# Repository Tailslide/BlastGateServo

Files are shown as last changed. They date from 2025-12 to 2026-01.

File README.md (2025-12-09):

# BlastGateServo
Blast gate servo controller for Arduino

See 3d printed parts at : https://www.thingiverse.com/thing:3301904

## Features
* Allows a single push button to switch between different blast gates, with only a single one open at a time
* Currently open blast gate is indicated by an LED
* Optional automatic control using AC current sensors to detect active tools
* Debug output support for troubleshooting
* Configurable servo positions for precise gate control

## Hardware Requirements
* Arduino Uno (R3 or R4)
* A servo for each blast gate (up to 5)
* One push button
* Optional: An LED for each blast gate
* Optional: AC current sensors from https://moderndevice.com/products/current-sensor

## Development Setup
1. Install Visual Studio Code
2. Install PlatformIO IDE extension for VSCode
3. Open this project folder in VSCode
4. PlatformIO will automatically install required dependencies:
   - Servo library (v1.2.1 or later)

## Building and Uploading
1. Connect your Arduino Uno to your computer via USB
2. In VSCode:
   - Click the PlatformIO icon in the sidebar
   - Under Project Tasks:
     - Click "Build" to compile
     - Click "Upload" to flash to Arduino
   - Use "Monitor" to view serial output (when debugging is enabled)
3. Serial monitor is configured at 9600 baud

## Operation Modes
* Normal Mode: Use the push button to cycle through gates. After selecting a gate, wait briefly and it will open automatically.
* Meter Mode: For calibrating AC sensors:
  1. Power off the Arduino
  2. Press and hold the button
  3. While holding the button, power on the Arduino
  4. Release the button after power-up
  5. LEDs will now act as signal strength indicators:
     - Each LED corresponds to an AC sensor
     - Turn on a device on the cable being calibrated
     - Rotate the sensor clamp around the cable
     - LED will blink faster (or become solid) when sensor is optimally positioned
* Debug Mode: Enable detailed serial output by setting DEBUG flag (enabled by default)
* LED Test Mode: Enable by uncommenting DEBUG_LED_TEST in Configuration.h. Flashes each LED in sequence to verify connections.
* Servo Test Mode: Enable by uncommenting DEBUG_SERVO_TEST in Configuration.h. Opens and closes a specified servo with each button press without initializing other components. Set TEST_SERVO_INDEX in Configuration.h to select which servo to test (1 = first servo, 2 = second servo, etc.). Useful for testing servo functionality and calibration. The system will properly handle disabled servos (pins set to -1) by controlling only the LED while skipping servo movement.

## Configuration
All settings can be adjusted in Configuration.h:

### Basic Settings
* Number of gates (NUM_GATES) - up to 5 supported
* Number of AC sensors (NUM_AC_SENSORS) - typically one per gate
* Number of LEDs (NUM_LEDS) - typically one per gate
* Button pin assignment (BUTTON_PIN)

### Timing Settings
* CLOSE_DELAY - Time it takes for a gate to close (ms)
* OPEN_DELAY - Time after last button push to open gate (ms)
* MAX_BLINK_LEN - LED blink rate (adjusted automatically in debug mode)

### AC Sensor Settings
* NUM_OFF_SAMPLES - Number of samples for checking average sensor off values
* NUM_OFF_MAX_SAMPLES - Milliseconds to sample for max off value at startup
* AVG_READINGS - Number of readings to average when triggering gates (max 50)
* AC_SENSOR_SENSITIVITY - Trigger threshold multiplier (2.0 = twice max off reading)

### Flutter Protection Settings
The system includes comprehensive protection against AC sensor flutter that could cause rapid servo cycling and potential hardware damage:

* **AC_SENSOR_SENSITIVITY_ON** (default: 2.0) - Threshold multiplier to turn tool ON
* **AC_SENSOR_SENSITIVITY_OFF** (default: 1.5) - Threshold multiplier to turn tool OFF (creates hysteresis)
* **DEBOUNCE_STABLE_READINGS** (default: 3) - Number of consecutive stable readings required before state change
* **MIN_SERVO_INTERVAL_MS** (default: 2000) - Minimum milliseconds between operations on the same gate
* **MAX_OPS_PER_MINUTE** (default: 10) - Maximum operations per minute before emergency shutdown
* **ERROR_FLASH_INTERVAL_MS** (default: 200) - LED flash interval when in error state

#### How Flutter Protection Works
1. **Hysteresis**: Uses different thresholds for turning ON (2.0x baseline) vs turning OFF (1.5x baseline) to prevent rapid toggling around a single threshold
2. **Debouncing**: Requires 3 consecutive stable sensor readings before changing gate state, filtering out momentary noise spikes
3. **Minimum Interval with Queuing**: Enforces 2-second minimum between operations on the same gate
   - If a gate operation is requested during the cooldown period, it is automatically queued
   - The queued operation executes automatically once the minimum interval expires
   - This ensures responsive operation while preventing rapid cycling
   - Example: If you turn on a tool immediately after turning it off, the gate will open automatically 2 seconds later
4. **Rate Limiting**: Tracks operations per minute and enters error state if limit exceeded
5. **Error State**: When too many operations detected (flutter condition):
   - All LEDs flash rapidly in error pattern
   - All automatic gate operations are disabled
   - System requires restart to recover
   - Alerts user to problematic sensor or configuration issue

### Pin Assignments
* Servo pins (SERVO_PIN_1 through SERVO_PIN_5)
  * Set any servo pin to -1 to disable that servo while maintaining the gate numbering
  * Example: Setting SERVO_PIN_2 to -1 disables the second servo but keeps gate 3 as "gate 3" in the UI
* AC sensor pins (AC_SENSOR_PIN_1 through AC_SENSOR_PIN_5)
* LED pins (LED_PIN_1 through LED_PIN_5)

### Servo Position Configuration
* SERVO_MAX_x - Maximum position for each servo (typically 180 degrees)
* SERVO_MIN_x - Minimum position for each servo (typically 0 degrees)
* GATE_CLOSED_AT_MAX_x - Determines gate orientation:
  * Set to true (default) if gate is closed when servo is at max position
  * Set to false if gate is open when servo is at max position (inverted)
* Set any servo's MAX/MIN values even if the pin is disabled (-1) to maintain consistent configuration

## Project Structure
* src/BlastGateServo.cpp - Main program file with setup and loop
* include/Configuration.h - All user configurable settings
* include/GateServos.h/cpp - Servo control and position management
* include/AcSensors.h/cpp - AC current sensor reading and threshold detection
* include/Debug.h - Debug output macros and configuration
* platformio.ini - PlatformIO project configuration and library dependencies

## Changes
* Created 2019-01-02 - Greg Pringle
* Updated 2019-01-20 - Greg Pringle - Added AC sensor support
* Updated 2025-01-26 - Added VSCode/PlatformIO support
* Updated 2025-02-16 - Added detailed configuration documentation and converted to proper C++ structure
* Updated 2025-02-26 - Added support for disabling specific servos (set pin to -1) while maintaining gate numbering
* Updated 2025-02-26 - Fixed button timing logic to properly open gates after selection
* Updated 2025-02-26 - Improved timer logic to ensure gates open/close reliably, reduced OPEN_DELAY to 800ms
* Updated 2025-02-26 - Implemented proper button debouncing and state machine for more reliable operation
* Updated 2025-02-26 - Fixed issue with servos not moving when button was pressed
* Updated 2025-02-26 - Enhanced gate selection to automatically skip disabled gates when cycling through options
* Updated 2025-02-27 - Fixed compiler warnings in Configuration.h (removed redundant header guard and corrected version number format) and in GateServos.h (fixed signed/unsigned comparison by changing opendelay type to unsigned long)
* Updated 2025-02-27 - Added gate orientation configuration (GATE_CLOSED_AT_MAX_x) to support different physical gate setups where gates may be open when up or closed when up
* Updated 2025-12-08 - Implemented comprehensive flutter protection system to prevent AC sensor flutter from damaging hardware:
  - Added hysteresis (different ON/OFF thresholds) to prevent rapid state toggling
  - Implemented debouncing requiring 3 consecutive stable readings before state change
  - Added minimum 2-second interval between servo operations on same gate with automatic queuing
  - Operations requested during cooldown are queued and execute automatically when interval expires
  - Implemented rate limiting with emergency shutdown if more than 10 operations per minute
  - Added error state with flashing LED pattern and system halt on flutter detection
  - All protection settings are configurable in Configuration.h

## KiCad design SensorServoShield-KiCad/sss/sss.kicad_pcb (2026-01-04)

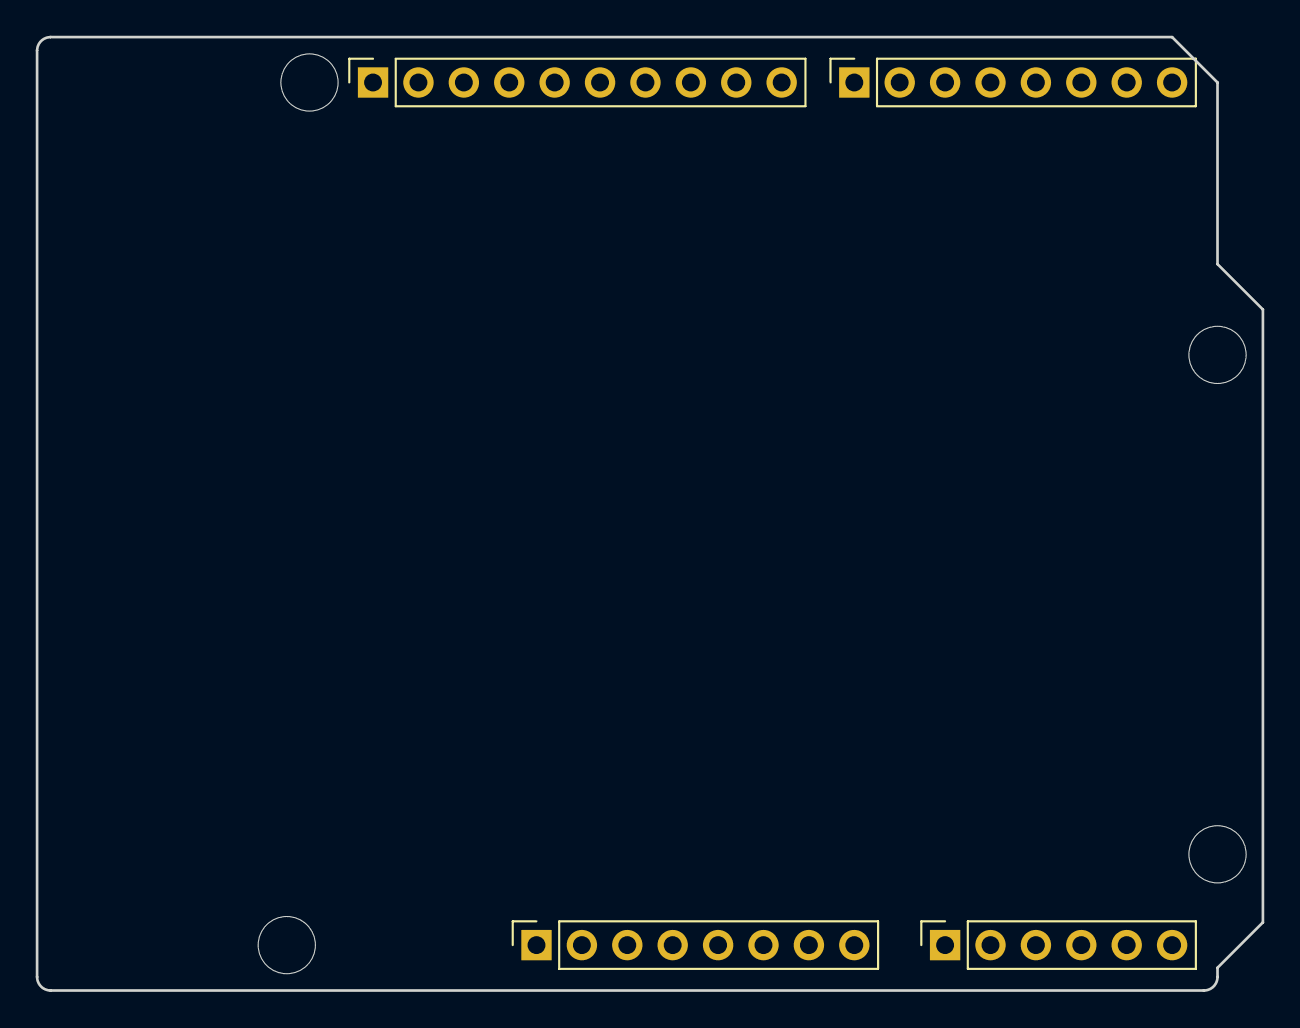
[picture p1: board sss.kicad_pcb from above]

Board: 2 copper layers, 68.6 x 53.3 mm, 8 parts (0 on the bottom side), 3 nets, no tracks yet.

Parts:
J1: Power; PinSocket_1x08_P2.54mm_Vertical
J2: Digital/PWM; PinSocket_1x10_P2.54mm_Vertical
J3: Analog; PinSocket_1x06_P2.54mm_Vertical
J4: Digital/PWM; PinSocket_1x08_P2.54mm_Vertical
MH1, MH2, MH3, MH4: MountingHole_3.2mm

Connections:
/SCL/A5: J2.1, J3.6
/SDA/A4: J2.2, J3.5
GND: J1.6, J1.7, J2.4

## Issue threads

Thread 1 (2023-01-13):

Trying to recognize all areas to configure

MakerMatt46307, 2023-01-13:
I have been studying your code, I am new to arduino programming, and have found your coding very helpful.

Could you let me know if I am going to make the program unusable by modifying the following attributes:

1. No current sensors
2. Create "if" logic to turn on my dust collector when a gate is fully opened then off when a gate is about to close.
3. Cheers!
Thanks!

Tailslide, 2023-01-13:
That should work fine as long as you have some way of turning on your dust collector.  I know you can buy power bars that can be controlled by arduino, or if your board has wifi you could look into a wifi outlet.

I went the simpler way and hook my tools up to something like this to make it turn on with the tool. They make 220v versions too.
https://www.busybeetools.com/products/switch-i-vac-vacuum.html

MakerMatt46307, 2023-01-15:
I found one that operates at low voltage and relays 120v. Should work fine, thanks for the suggestion. Not really wanting automated on/off as a lot of my auto and motorcycle activity needs Alexa to turn on the dust removal. I’ll figure that out after I get all of the servos and lights.

One more Sunday morning thing for you, curious as to where I will insert the code in your program as to trigger on/off the relay for the fan. Can you help me so I don’t mess up your logic?

I was also thinking of going analog for this function and just putting in a contact switch at the blast gate in the open position that would complete the low voltage circuit and trigger the relay.

Thanks again and thanks for responding. A lot of references I read go silent over time or authors don’t finish or update on the finished project.

Matt

Matt McClay

708-941-8777
________________________________
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

Tailslide, 2025-03-11:
Closing this issue since there's been a major rewrite since.

Closed 2025-03-11.

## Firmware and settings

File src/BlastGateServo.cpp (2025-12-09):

#include <Arduino.h>
#include <Servo.h>
#include "Debug.h"
#include "Configuration.h"
#include "GateServos.h"
#include "AcSensors.h"

/*  Blast gate servo controller for Arduino
 *   
 *   Allows a single push button to switch between different blast gates, with only a single one open at a time.
 *   Currently open blast gate is indicated by an LED.
 *    
 *   Requires:  A servo for each blast gate, one button
 *   Optional: An LED for each blast gate
 *   
 *   In the future I plan on adding an option to automate this based on detected AC current from the tool
 *   (if my sensor ever shows up)
 *   
 *   Created 2019-01-02 - Greg Pringle
 *   Updated 2019-01-20 - Greg Pringle - Refactored, added support for AC current sensor
 */

int buttonState = 0;         // variable for reading the pushbutton status
int curselectedgate = -1;    // Currently selected gate (-1 = all closed)
bool metermode = false;      // Meter mode flag
bool toolon = false;         // indicates if there is any current sensed

// Button handling variables
int lastButtonState = HIGH;  // Previous button state (HIGH = not pressed with pull-up)
unsigned long lastDebounceTime = 0;  // Last time button state changed
unsigned long debounceDelay = 50;    // Debounce time in milliseconds
unsigned long gateOpenTimer = 0;     // Timer for gate opening delay
bool gateSelectionActive = false;    // Flag to indicate a gate has been selected and waiting to open

static const bool has_button = HAS_BUTTON;
static const int buttonPin = BUTTON_PIN;
static const bool hasbutton = HAS_BUTTON;  

GateServos gateservos(-1);  // object controlling blast gate servos
AcSensors acsensors;        // object controlling AC current sensors

void setup() {
  #ifdef DEBUG
  Serial.begin(9600);
  delay(1000);  // Give serial connection time to establish
  DPRINTLN("BlastGateServo starting...");
  #endif

  // Set up button pin for all modes
  if (has_button) {
      pinMode(buttonPin, INPUT_PULLUP);
      delay(100); // Give pin time to stabilize
      
      // Initialize button state to prevent false detection at startup
      buttonState = digitalRead(buttonPin);
      lastButtonState = buttonState;
      lastDebounceTime = millis();
      gateSelectionActive = false;
      gateOpenTimer = 0;
      
      DPRINTLN("Button initialized");
  }

  #ifdef DEBUG_SERVO_TEST
  // For servo test mode, we only need to set up the button
  // and initialize the servo pin for the selected servo
  DPRINT("Servo Test Mode Active - Press button to toggle servo ");
  DPRINTLN(TEST_SERVO_INDEX);
  
  // Initialize just the LED pin for the selected servo
  int ledPin;
  // Adjust for 1-based indexing in display but 0-based indexing in arrays
  switch(TEST_SERVO_INDEX - 1) {
    case 0: ledPin = LED_PIN_1; break;
    case 1: ledPin = LED_PIN_2; break;
    case 2: ledPin = LED_PIN_3; break;
    case 3: ledPin = LED_PIN_4; break;
    case 4: ledPin = LED_PIN_5; break;
    default: ledPin = LED_PIN_1; break;
  }
  
  pinMode(ledPin, OUTPUT);
  digitalWrite(ledPin, LOW);
  
  // Skip all other initialization
  return;
  #endif

  // Check for meter mode
  if (has_button && digitalRead(buttonPin) == LOW) {
      metermode = true;
      DPRINTLN("Entering meter mode - Use LEDs to calibrate AC sensor positions");
  } else {
      metermode = false;
  }

  #ifdef DEBUGMETER
      metermode = true;
  #endif
  
  #ifdef DEBUG_SENSOR_TEST
      metermode = true;
      DPRINTLN("Entering sensor test mode");
  #endif

  // Initialize sensors before anything else
  acsensors.InitializeSensors();

  // Initialize gates if not in meter mode
  if (!metermode) {
      gateservos.initializeGates();
  }

  #if !ENABLE_AC_SENSORS
  // Print this message only once during setup
  DPRINTLN("AC sensors disabled - using manual control only");
  #endif

  #ifdef DEBUG_LED_TEST
  // Initialize LED pins for test mode
  pinMode(LED_PIN_1, OUTPUT);
  pinMode(LED_PIN_2, OUTPUT);
  pinMode(LED_PIN_3, OUTPUT);
  pinMode(LED_PIN_4, OUTPUT);
  pinMode(LED_PIN_5, OUTPUT);
  
  // Start with all LEDs off
  digitalWrite(LED_PIN_1, LOW);
  digitalWrite(LED_PIN_2, LOW);
  digitalWrite(LED_PIN_3, LOW);
  digitalWrite(LED_PIN_4, LOW);
  digitalWrite(LED_PIN_5, LOW);
  
  DPRINTLN("LED Test Mode Active - Press button to light all LEDs");
  #endif
  // Note: Removed duplicate initialization
}


void loop()
{
  // Check for error state and display error pattern
  if (gateservos.isInErrorState()) {
    // Flash all LEDs rapidly to indicate error
    static unsigned long lastFlash = 0;
    static bool flashState = false;
    
    if (millis() - lastFlash >= ERROR_FLASH_INTERVAL_MS) {
      flashState = !flashState;
      lastFlash = millis();
      
      // Flash all LEDs
      for (int i = 0; i < gateservos.num_gates; i++) {
        if (flashState) {
          gateservos.ledon(i);
        } else {
          gateservos.ledoff(i);
        }
      }
      
      // Print error message periodically (every 10 flashes)
      static int flashCount = 0;
      flashCount++;
      if (flashCount >= 10) {
        DPRINTLN("ERROR STATE: System halted due to excessive servo operations");
        DPRINTLN("Restart required to resume operation");
        flashCount = 0;
      }
    }
    
    // Do not process any other logic when in error state
    return;
  }
  
  #ifdef DEBUG_LED_TEST
  // LED test pattern - flash each LED in sequence or all on when button pressed
  static int currentLed = 0;
  static unsigned long lastChange = 0;
  const int testDelay = 500; // 500ms on/off time

  // Check button state (LOW when pressed due to pull-up resistor)
  int btnState = digitalRead(BUTTON_PIN);
  DPRINT("Button state: ");
  DPRINTLN(btnState);
  
  if (btnState == LOW) {
    // Button pressed (reads LOW with pull-up) - turn on all LEDs
    digitalWrite(LED_PIN_1, HIGH);
    digitalWrite(LED_PIN_2, HIGH);
    digitalWrite(LED_PIN_3, HIGH);
    digitalWrite(LED_PIN_4, HIGH);
    digitalWrite(LED_PIN_5, HIGH);
  } else {
    // Button not pressed - do sequential pattern
    if (millis() - lastChange >= testDelay) {
      // Turn off all LEDs first
      digitalWrite(LED_PIN_1, LOW);
      digitalWrite(LED_PIN_2, LOW);
      digitalWrite(LED_PIN_3, LOW);
      digitalWrite(LED_PIN_4, LOW);
      digitalWrite(LED_PIN_5, LOW);

      // Turn on only the current LED
      switch(currentLed) {
        case 0: digitalWrite(LED_PIN_1, HIGH); break;
        case 1: digitalWrite(LED_PIN_2, HIGH); break;
        case 2: digitalWrite(LED_PIN_3, HIGH); break;
        case 3: digitalWrite(LED_PIN_4, HIGH); break;
        case 4: digitalWrite(LED_PIN_5, HIGH); break;
      }

      // Move to next LED
      currentLed = (currentLed + 1) % 5; // Use explicit 5 instead of NUM_LEDS
      lastChange = millis();
    }
  }
  return; // Skip normal operation when in LED test mode
  #endif

  #ifdef DEBUG_SERVO_TEST
  // Servo test mode - open/close selected servo with button press
  static bool servoOpen = false;
  static bool lastButtonState = HIGH;
  static Servo testServo;  // Local servo object for test mode
  
  // Get the pin configurations for the selected servo
  static int servoPin, servoMax, servoMin, ledPin;
  static bool configPrinted = false;
  
  // Only set up the configuration once
  if (!configPrinted) {
    // Adjust for 1-based indexing in display but 0-based indexing in arrays
    switch(TEST_SERVO_INDEX - 1) {
      case 0:
        servoPin = SERVO_PIN_1;
        servoMax = SERVO_MAX_1;
        servoMin = SERVO_MIN_1;
        ledPin = LED_PIN_1;
        break;
      case 1:
        servoPin = SERVO_PIN_2;
        servoMax = SERVO_MAX_2;
        servoMin = SERVO_MIN_2;
        ledPin = LED_PIN_2;
        break;
      case 2:
        servoPin = SERVO_PIN_3;
        servoMax = SERVO_MAX_3;
        servoMin = SERVO_MIN_3;
        ledPin = LED_PIN_3;
        break;
      case 3:
        servoPin = SERVO_PIN_4;
        servoMax = SERVO_MAX_4;
        servoMin = SERVO_MIN_4;
        ledPin = LED_PIN_4;
        break;
      case 4:
        servoPin = SERVO_PIN_5;
        servoMax = SERVO_MAX_5;
        servoMin = SERVO_MIN_5;
        ledPin = LED_PIN_5;
        break;
      default:
        servoPin = SERVO_PIN_1;
        servoMax = SERVO_MAX_1;
        servoMin = SERVO_MIN_1;
        ledPin = LED_PIN_1;
        break;
    }
    
    // Print debug info about the selected servo (only once)
    DPRINT("Servo ");
    DPRINT(TEST_SERVO_INDEX);
    DPRINT(" configuration - Pin: ");
    DPRINT(servoPin);
    DPRINT(", Max (closed): ");
    DPRINT(servoMax);
    DPRINT(", Min (open): ");
    DPRINTLN(servoMin);
    
    // Add a warning if the servo pin is disabled
    if (servoPin == -1) {
      DPRINTLN("WARNING: Selected servo pin is disabled (-1)");
      DPRINTLN("LED will still work but servo will not move");
    }
    
    configPrinted = true;
  }
  
  // Check button state (LOW when pressed due to pull-up resistor)
  int btnState = digitalRead(BUTTON_PIN);
  
  // Button state changed from HIGH to LOW (button pressed)
  if (btnState == LOW && lastButtonState == HIGH) {
    DPRINTLN("Button pressed in servo test mode");
    
    // Toggle servo state and LED
    if (servoOpen) {
      // Close the servo
      DPRINT("Closing servo ");
      DPRINT(TEST_SERVO_INDEX);
      DPRINT(" - Setting position to ");
      DPRINTLN(servoMax);
      digitalWrite(ledPin, LOW);
      
      // Only control the servo if the pin is valid (not -1)
      if (servoPin != -1) {
        // Direct servo control without using gateservos
        testServo.attach(servoPin);
        testServo.write(servoMax);
        delay(CLOSE_DELAY);
        testServo.detach();
        DPRINTLN("Servo closed");
      } else {
        DPRINTLN("Skipped servo (pin disabled)");
        delay(CLOSE_DELAY); // still delay for consistency
      }
      
      servoOpen = false;
    } else {
      // Open the servo
      DPRINT("Opening servo ");
      DPRINT(TEST_SERVO_INDEX);
      DPRINT(" - Setting position to ");
      DPRINTLN(servoMin);
      digitalWrite(ledPin, HIGH);
      
      // Only control the servo if the pin is valid (not -1)
      if (servoPin != -1) {
        // Direct servo control without using gateservos
        testServo.attach(servoPin);
        testServo.write(servoMin);
        delay(OPEN_DELAY);
        testServo.detach();
        DPRINTLN("Servo opened");
      } else {
        DPRINTLN("Skipped servo (pin disabled)");
        delay(OPEN_DELAY); // still delay for consistency
      }
      
      servoOpen = true;
    }
    
    delay(200); // Debounce delay
  }
  
  lastButtonState = btnState;
  return; // Skip normal operation when in servo test mode
  #endif

  bool toolon = false; // indicates if there is any current sensed
  
  // Process any queued servo operations (flutter protection)
  gateservos.processQueuedOperations();

  #if ENABLE_AC_SENSORS
  // Only process AC sensors if they are enabled
  acsensors.ReadSensors(); // read all the AC current sensors
  
  if (metermode) {
      acsensors.DisplayMeter();  // if user put device into meter mode, use LED lights to display sensor signal.
      return; // Don't process any other logic in meter mode
  }
  else // not meter mode
  {
    for (int cursensor=0; cursensor < acsensors.num_ac_sensors && cursensor < NUM_AC_SENSORS; cursensor++)
    {
        // This sensor is triggered by power tool
        //
        if (acsensors.Triggered(cursensor))
        {
          // this tool is active, output info to debug
          DPRINT(" TOOL ON #"); DPRINT(cursensor); DPRINT(" OFF READING:"); DPRINT(acsensors.GetOffReading(cursensor)); DPRINT(" AVG SENSOR READING:"); DPRINTLN(acsensors.GetAvgReading(cursensor));

          // ignore button if tool detected
          gateSelectionActive = false;
          toolon = true;
          if (curselectedgate != cursensor) curselectedgate = cursensor;

          // Gate hasn't been opened yet, open it
          if (gateservos.gateopen[cursensor] != true)
          {
            gateservos.gateopen[cursensor] = true;
            gateservos.ledon(cursensor);
            gateservos.opengate(cursensor);
          }
        }
        else
        {
          // this tool is not active and gate hasn't been closed yet. Close it.
          if (gateservos.gateopen[cursensor])
          {
            gateservos.gateopen[cursensor] = false;
            gateservos.ledoff(cursensor);
            DPRINT(" TOOL OFF #"); DPRINTLN(cursensor);
            gateservos.closegate(cursensor);
            curselectedgate = gateservos.firstgateopen();  // change currently active gate to first open one
          }
        }
    }
  }
  #else
  // AC sensors are disabled, only manual control is available
  // Debug message moved to setup
  #endif

    // Button handling with debounce and state machine
    if (hasbutton && !toolon) {
      // Read the current button state
      int reading = digitalRead(buttonPin);
      
      // Check if button state has changed
      if (reading != lastButtonState) {
        // Reset debounce timer
        lastDebounceTime = millis();
      }
      
      // If button state has been stable for debounce period
      if ((millis() - lastDebounceTime) > debounceDelay) {
        // If button state has changed since last stable reading
        if (reading != buttonState) {
          buttonState = reading;
          
          // Button pressed (LOW with pull-up resistor)
          if (buttonState == LOW) {
            // Show the previous selection before changing it
            if (curselectedgate == -1) {
              DPRINTLN("Button Pressed - Previous selection: All gates closed");
            } else {
              DPRINT("Button Pressed - Previous selection: Gate #");
              DPRINTLN(curselectedgate + 1);
            }
            
            // Turn off LED for previous selection
            gateservos.ledoff(curselectedgate);
            
            // Move to next gate, skipping disabled gates
            do {
              curselectedgate++;
              if (curselectedgate == gateservos.num_gates)
                curselectedgate = -1;
            } while (curselectedgate >= 0 && gateservos.isGateDisabled(curselectedgate));
            
            // Turn on LED for the selected gate (if not "all closed" option)
            if (curselectedgate >= 0)
              gateservos.ledon(curselectedgate);
            
            // Display new selection that will be opened after delay
            if (curselectedgate == -1) {
              DPRINTLN("New selection: All gates closed (will close all gates after delay)");
            } else {
              DPRINT("New selection: Gate #");
              DPRINTLN(curselectedgate + 1);
              DPRINTLN("(will open after delay)");
            }
          }
          // Button released (HIGH with pull-up resistor)
          else if (buttonState == HIGH) {
            DPRINTLN("Button released, starting gate open timer");
            gateSelectionActive = true;
            gateOpenTimer = millis();
          }
        }
      }
      
      // Update last button state
      lastButtonState = reading;
      
      // If a gate is selected and we're waiting for the delay to open it
      if (gateSelectionActive) {
        // Calculate elapsed time
        unsigned long elapsedTime = millis() - gateOpenTimer;
        
        // Debug output every 200ms to avoid flooding serial
        if (elapsedTime % 200 < 50) {
          DPRINT("Timer: ");
          DPRINTLN(elapsedTime);
          
          DPRINT("Current selected gate: ");
          if (curselectedgate == -1) {
            DPRINTLN("All gates closed");
          } else {
            DPRINTLN(curselectedgate + 1);
          }
          
          DPRINT("Current open gate: ");
          if (gateservos.curopengate == -1) {
            DPRINTLN("None");
          } else {
            DPRINTLN(gateservos.curopengate + 1);
          }
          
          DPRINT("Threshold: ");
          DPRINTLN(gateservos.opendelay);
        }
        
        // Open the gate when we reach the threshold
        if (elapsedTime >= gateservos.opendelay) {
          DPRINTLN("Opening gate after delay");
          
          // Debug the gate we're about to open
          if (curselectedgate == -1) {
            DPRINTLN("Opening: All gates closed");
          } else {
            DPRINT("Opening: Gate #");
            DPRINTLN(curselectedgate + 1);
          }
          
          // Call the function to open/close gates
          gateservos.ManuallyOpenGate(curselectedgate);
          
          // Reset gate selection
          gateSelectionActive = false;
        }
      }
    }
  
  if (metermode)
   delay(1);  // minimal delay while metering so we can collect as many samples as possible
  else
   delay(50);
  
}

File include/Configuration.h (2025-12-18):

#ifndef CONFIGURATION_H
#define CONFIGURATION_H_VERSION 1

// All user defined settings required to configure operation are in this file

//#ifndef DEBUG
//#define DEBUG   //Enable debug output - set this in platformio.ini instead
//#endif
//#define DEBUGMETER // debug meter mode for placing sensors on cables
//#define DEBUG_METER_VERBOSE // Enable verbose debug output in meter mode (slows down LED blinking)
//#define DEBUG_LED_TEST // Enable LED test mode - flashes LEDs in sequence
//#define DEBUG_SERVO_TEST // Enable servo test mode - opens/closes a servo with button press
#define TEST_SERVO_INDEX 1 // Which servo to test (1 = first servo, 2 = second servo, etc.)
//#define DEBUG_SENSOR_TEST // Enable sensor test mode - display raw readings for a specific sensor
//#define TEST_SENSOR_INDEX 1 // Which sensor to test (1 = first sensor, 2 = second sensor, etc.)

// Set to false to disable AC sensor functionality (manual button control only)
#define ENABLE_AC_SENSORS true


// servo stuff 
#define CLOSE_DELAY 1000 // how long it takes a gate to close
#define OPEN_DELAY 800 // how long after last button push to open gate

#define HAS_BUTTON true  // true if button is attached
#define BUTTON_PIN 13    // the number of the pushbutton pin

/// current Sensor stuff
#define NUM_AC_SENSORS 5        // Number of AC sensors connected.. currently only handles 1 per gate
#define NUM_LEDS 5              // Number of LEDs connected.. optional but should be 1 per gate
#define NUM_GATES 5             // Number of blast gates with servos connected
#define NUM_OFF_SAMPLES 50      // number of samples when checking avg sensor off values (unused)
#define NUM_OFF_MAX_SAMPLES 500 // Milliseconds to sample for max off value for each gate when starting up
#define AVG_READINGS 25         // number of readings to average when triggering gates.. higher number is more accurate but more delay ( no more than 50)
#define AC_SENSOR_SENSITIVITY 2.0 // Triggers on twice the max readings of the off setting. The closer to one, the more sensitive

// Flutter Protection Settings
#define AC_SENSOR_SENSITIVITY_ON  2.0  // Threshold to turn tool ON (same as AC_SENSOR_SENSITIVITY for backward compatibility)
#define AC_SENSOR_SENSITIVITY_OFF 1.5  // Threshold to turn tool OFF (hysteresis prevents rapid toggling)
#define DEBOUNCE_STABLE_READINGS  3    // Number of consecutive stable readings required before state change
#define MIN_SERVO_INTERVAL_MS     2000 // Minimum milliseconds between servo operations on same gate
#define MAX_OPS_PER_MINUTE        10   // Maximum operations per minute before emergency shutdown
#define ERROR_FLASH_INTERVAL_MS   200  // LED flash interval in error state (milliseconds)


// Blink timing for meter mode (in milliseconds)
#ifdef DEBUG
#define MAX_BLINK_LEN 50  // faster blink in debug mode to compensate for serial delay
#else
#define MAX_BLINK_LEN 200 // normal blink rate in release mode
#endif

// Servo Pins
#define SERVO_PIN_1 12 // Pin for first blast gate servo
#define SERVO_PIN_2 -1 // ...etc..
#define SERVO_PIN_3 11
#define SERVO_PIN_4 9
#define SERVO_PIN_5 8
#define SERVO_PIN_6 -1
#define SERVO_PIN_7 -1
#define SERVO_PIN_8 -1

// AC Sensor Pins
#define AC_SENSOR_PIN_1 A0 // Pin for first AC sensor
#define AC_SENSOR_PIN_2 -1 //A1 // ..etc...
#define AC_SENSOR_PIN_3 A2
#define AC_SENSOR_PIN_4 A3
#define AC_SENSOR_PIN_5 A4 //A4
#define AC_SENSOR_PIN_6 -1
#define AC_SENSOR_PIN_7 -1
#define AC_SENSOR_PIN_8 -1

// Gate orientation configuration
// Set to true if gate is closed when servo is at max position (default)
// Set to false if gate is open when servo is at max position (inverted)
#define GATE_CLOSED_AT_MAX_1 false
#define GATE_CLOSED_AT_MAX_2 false
#define GATE_CLOSED_AT_MAX_3 false
#define GATE_CLOSED_AT_MAX_4 false
#define GATE_CLOSED_AT_MAX_5 false
#define GATE_CLOSED_AT_MAX_6 false
#define GATE_CLOSED_AT_MAX_7 false
#define GATE_CLOSED_AT_MAX_8 false

// Servo Max positions (180 degrees)
// It's ok to leave at default and for the servo to try to go too far but it will increase the power load
//
#define SERVO_MAX_1 180
#define SERVO_MAX_2 180
#define SERVO_MAX_3 180
#define SERVO_MAX_4 180
#define SERVO_MAX_5 180
#define SERVO_MAX_6 -1
#define SERVO_MAX_7 -1
#define SERVO_MAX_8 -1

// Servo Min positions (0 degrees)
// It's ok to leave at default and for the servo to try to go too far but it will increase the power load
//
#define SERVO_MIN_1 0
#define SERVO_MIN_2 0
#define SERVO_MIN_3 0
#define SERVO_MIN_4 0
#define SERVO_MIN_5 0
#define SERVO_MIN_6 -1
#define SERVO_MIN_7 -1
#define SERVO_MIN_8 -1



// LED pins
#define LED_PIN_1 6  // Pin for first LED indicator
#define LED_PIN_2 -1 //2  // ...etc..
#define LED_PIN_3 3
#define LED_PIN_4 4
#define LED_PIN_5 5
#define LED_PIN_6 -1
#define LED_PIN_7 -1
#define LED_PIN_8 -1


#endif // CONFIGURATION_H

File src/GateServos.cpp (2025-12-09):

#include "Arduino.h"
#include <Servo.h>
#include "Debug.h"
#include "Configuration.h"
#include "GateServos.h"

  // Constructor.. usually called with -1 to indicate no gates are open
  //
  GateServos::GateServos(int initcuropengate)
  {
    curopengate = initcuropengate;
    
    // Initialize operation times buffer
    for (int i = 0; i < maxOpsPerMinute; i++) {
      operationTimes[i] = 0;
    }
    
    // Initialize queued operations
    for (int i = 0; i < 8; i++) {
      queuedOps[i].pending = false;
      queuedOps[i].gatenum = -1;
      queuedOps[i].isOpen = false;
      queuedOps[i].requestTime = 0;
    }
  }

  //////////////////////////////////////////////////////////////////////
  // checkOperationAllowed(int gatenum)
  //
  // Check if a servo operation is allowed based on flutter protection rules
  // Returns true if operation can execute immediately
  // Returns false if operation should be queued or blocked
  //////////////////////////////////////////////////////////////////////
  bool GateServos::checkOperationAllowed(int gatenum)
  {
    // Don't allow operations if in error state
    if (errorState) {
      DPRINTLN("Operation blocked: System in error state");
      return false;
    }
    
    unsigned long currentTime = millis();
    
    // Check rate limiting first - count operations in last minute
    unsigned long oneMinuteAgo = currentTime - 60000;
    int recentOps = 0;
    for (int i = 0; i < maxOpsPerMinute; i++) {
      if (operationTimes[i] > oneMinuteAgo) {
        recentOps++;
      }
    }
    
    if (recentOps >= maxOpsPerMinute) {
      // Too many operations - enter error state
      errorState = true;
      DPRINTLN("CRITICAL ERROR: Too many servo operations detected!");
      DPRINT("Operations in last minute: ");
      DPRINTLN(recentOps);
      DPRINTLN("System entering error state - restart required");
      return false;
    }
    
    // Check minimum interval between operations on same gate
    if (currentTime - lastOperationTime[gatenum] < minServoInterval) {
      DPRINT("Operation too soon for gate #");
      DPRINT(gatenum + 1);
      DPRINT(" (");
      DPRINT(currentTime - lastOperationTime[gatenum]);
      DPRINT("ms < ");
      DPRINT(minServoInterval);
      DPRINTLN("ms) - will be queued");
      return false;
    }
    
    return true;
  }

  //////////////////////////////////////////////////////////////////////
  // recordOperation(int gatenum)
  //
  // Record a servo operation for rate limiting tracking
  //////////////////////////////////////////////////////////////////////
  void GateServos::recordOperation(int gatenum)
  {
    unsigned long currentTime = millis();
    lastOperationTime[gatenum] = currentTime;
    
    // Add to circular buffer
    operationTimes[operationIndex] = currentTime;
    operationIndex = (operationIndex + 1) % maxOpsPerMinute;
  }

  //////////////////////////////////////////////////////////////////////
  // isInErrorState()
  //
  // Check if the system is in error state
  //////////////////////////////////////////////////////////////////////
  bool GateServos::isInErrorState()
  {
    return errorState;
  }

  //////////////////////////////////////////////////////////////////////
  // queueOperation(int gatenum, bool isOpen)
  //
  // Queue an operation for delayed execution when minimum interval expires
  //////////////////////////////////////////////////////////////////////
  void GateServos::queueOperation(int gatenum, bool isOpen)
  {
    if (gatenum < 0 || gatenum >= 8) return;
    
    queuedOps[gatenum].gatenum = gatenum;
    queuedOps[gatenum].isOpen = isOpen;
    queuedOps[gatenum].requestTime = millis();
    queuedOps[gatenum].pending = true;
    
    DPRINT("Queued ");
    DPRINT(isOpen ? "OPEN" : "CLOSE");
    DPRINT(" operation for gate #");
    DPRINTLN(gatenum + 1);
  }

  //////////////////////////////////////////////////////////////////////
  // processQueuedOperations()
  //
  // Process any pending queued operations that can now execute
  // Should be called regularly from main loop
  //////////////////////////////////////////////////////////////////////
  void GateServos::processQueuedOperations()
  {
    if (errorState) return; // Don't process queue in error state
    
    unsigned long currentTime = millis();
    
    for (int i = 0; i < 8; i++) {
      if (!queuedOps[i].pending) continue;
      
      // Check if enough time has passed since last operation on this gate
      if (currentTime - lastOperationTime[i] >= minServoInterval) {
        DPRINT("Executing queued ");
        DPRINT(queuedOps[i].isOpen ? "OPEN" : "CLOSE");
        DPRINT(" for gate #");
        DPRINTLN(i + 1);
        
        // Clear the queue entry first to avoid recursion
        queuedOps[i].pending = false;
        
        // Execute the operation
        if (queuedOps[i].isOpen) {
          opengate(i);
        } else {
          closegate(i);
        }
      }
    }
  }

  // Open the given gate number
  //
  void GateServos::opengate(int gatenum)
  {
      // Check if operation is allowed (flutter protection)
      if (!checkOperationAllowed(gatenum)) {
        // Queue the operation for later execution
        queueOperation(gatenum, true);
        return;
      }
      
      DPRINT("OPENING GATE #");
      DPRINT(gatenum + 1); // Display as 1-based
      DPRINT(" SERVO PIN:");
      DPRINT(servopin[gatenum]);
      
      // Determine the correct position based on gate orientation
      int openPosition;
      if (gateClosedAtMax[gatenum]) {
        // Normal orientation: min = open, max = closed
        openPosition = minservo[gatenum];
      } else {
        // Inverted orientation: max = open, min = closed
        openPosition = maxservo[gatenum];
      }
      
      DPRINT(" VALUE:");
      DPRINT(openPosition);
      DPRINT(" DELAY:");
      DPRINT(opendelay);
      DPRINTLN("");
      
      curopengate = gatenum;
      digitalWrite(ledpin[gatenum], HIGH);
      
      // Only control the servo if the pin is valid (not -1)
      if (servopin[gatenum] != -1) {
        // Ensure the servo is properly attached
        myservo.attach(servopin[gatenum]);  // attaches the servo
        
        // Debug the servo position
        DPRINT("Setting servo to position: ");
        DPRINTLN(openPosition);
        
        // Move the servo to open position
        myservo.write(openPosition); //open gate
        
        // Wait for gate to open
        delay(opendelay);
        
        // Detach the servo to prevent jitter
        myservo.detach();
        
        DPRINTLN("OPENED GATE");
        
        // Record this operation for flutter protection
        recordOperation(gatenum);
      } else {
        DPRINTLN("SKIPPED SERVO (PIN DISABLED)");
        delay(opendelay); // still delay for consistency
      }
  }
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

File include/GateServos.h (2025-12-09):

/*
  GateServos.h - Library for operating blast gate servos
  Created by Greg Pringle 2019-01-20
  Released into the public domain.
*/
#ifndef GateServo_h
#define GateServo_h

#include "Arduino.h"
#include <Servo.h>
#include "Debug.h"
#include "Configuration.h"

  class GateServos {
    static const int num_servos = NUM_GATES;
    static const int num_leds = NUM_LEDS;
    static const int servo_pin_1 = SERVO_PIN_1;
    static const int servo_pin_2 = SERVO_PIN_2; 
    static const int servo_pin_3 = SERVO_PIN_3;
    static const int servo_pin_4 = SERVO_PIN_4;
    static const int servo_pin_5 = SERVO_PIN_5;
    static const int servo_pin_6 = SERVO_PIN_6;
    static const int servo_pin_7 = SERVO_PIN_7;
    static const int servo_pin_8 = SERVO_PIN_8;

    static const bool gate_closed_at_max_1 = GATE_CLOSED_AT_MAX_1;
    static const bool gate_closed_at_max_2 = GATE_CLOSED_AT_MAX_2;
    static const bool gate_closed_at_max_3 = GATE_CLOSED_AT_MAX_3;
    static const bool gate_closed_at_max_4 = GATE_CLOSED_AT_MAX_4;
    static const bool gate_closed_at_max_5 = GATE_CLOSED_AT_MAX_5;
    static const bool gate_closed_at_max_6 = GATE_CLOSED_AT_MAX_6;
    static const bool gate_closed_at_max_7 = GATE_CLOSED_AT_MAX_7;
    static const bool gate_closed_at_max_8 = GATE_CLOSED_AT_MAX_8;

    static const int servo_max_1 = SERVO_MAX_1;
    static const int servo_max_2 = SERVO_MAX_2;
    static const int servo_max_3 = SERVO_MAX_3;
    static const int servo_max_4 = SERVO_MAX_4;
    static const int servo_max_5 = SERVO_MAX_5;
    static const int servo_max_6 = SERVO_MAX_6;
    static const int servo_max_7 = SERVO_MAX_7;
    static const int servo_max_8 = SERVO_MAX_8;

    static const int servo_min_1 = SERVO_MIN_1;
    static const int servo_min_2 = SERVO_MIN_2;
    static const int servo_min_3 = SERVO_MIN_3;
    static const int servo_min_4 = SERVO_MIN_4;
    static const int servo_min_5 = SERVO_MIN_5;
    static const int servo_min_6 = SERVO_MIN_6;
    static const int servo_min_7 = SERVO_MIN_7;
    static const int servo_min_8 = SERVO_MIN_8;

    static const int led_pin_1 = LED_PIN_1;
    static const int led_pin_2 = LED_PIN_2;
    static const int led_pin_3 = LED_PIN_3;
    static const int led_pin_4 = LED_PIN_4;
    static const int led_pin_5 = LED_PIN_5;
    static const int led_pin_6 = LED_PIN_6;
    static const int led_pin_7 = LED_PIN_7;
    static const int led_pin_8 = LED_PIN_8;
    static const int closedelay = CLOSE_DELAY;
    
    // Flutter protection constants
    static const unsigned long minServoInterval = MIN_SERVO_INTERVAL_MS;
    static const int maxOpsPerMinute = MAX_OPS_PER_MINUTE;

    const int servopin[8] = {servo_pin_1,servo_pin_2,servo_pin_3,servo_pin_4,servo_pin_5,servo_pin_6,servo_pin_7,servo_pin_8};
    const int maxservo[8] = {servo_max_1,servo_max_2,servo_max_3,servo_max_4,servo_max_5,servo_max_6,servo_max_7,servo_max_8};
    const int minservo[8] = {servo_min_1,servo_min_2,servo_min_3,servo_min_4,servo_min_5,servo_min_6,servo_min_7,servo_min_8};
    const int ledpin[8] = {led_pin_1,led_pin_2,led_pin_3,led_pin_4,led_pin_5,led_pin_6,led_pin_7,led_pin_8}; // LED pins
    const bool gateClosedAtMax[8] = {gate_closed_at_max_1,gate_closed_at_max_2,gate_closed_at_max_3,gate_closed_at_max_4,gate_closed_at_max_5,gate_closed_at_max_6,gate_closed_at_max_7,gate_closed_at_max_8}; // Gate orientation
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

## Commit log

2019-01-21 Refactor, Add support for AC sensors
    Now supports clamp on AC current sensors from http://moderndevice.com/current.
    Also you can hold down the button to put LEDs into mode that blinks based on sensor input to make it easier to position them.
    [Configuration.h]
2025-01-26 Convert to PlatformIO
    [Configuration.h]
2025-02-18 Led and Button test working
    [Configuration.h]
2025-02-18 Fix meter mode... improve debug output
    [AcSensors.cpp, AcSensors.h, BlastGateServo.cpp]
2025-02-18 Meter mode working in release mode
    [Configuration.h]
2025-02-18 Fix blink in debg mode
    [Configuration.h]
2025-02-25 feat: add servo test mode for easier calibration
    [Configuration.h]
2025-02-26 feat: enhance servo test mode with multi-servo support
    [Configuration.h]
2025-02-26 feat: Add support for disabled servo pins
    [Configuration.h]
2025-02-26 fix: improve button handling and timing logic
    [Configuration.h]
2025-02-26 fix: Implement proper button debounce and gate logic
    [BlastGateServo.cpp, GateServos.cpp, GateServos.h]
2025-02-28 fix: correct header guard and type mismatch issues
    [Configuration.h]
2025-02-28 feat: add gate orientation configuration option
    [Configuration.h]
2025-12-08 fix: update sensor and gate handling to prevent out-of-bounds access
    [Configuration.h]
2025-12-08 feat: add verbose debug output for meter mode in AcSensors
    [Configuration.h]
2025-12-08 feat: add sensor test mode with detailed output for selected sensor
    [Configuration.h]
2025-12-08 fix: update sensor and LED pin configurations for better compatibility
    [Configuration.h]
2025-12-09 feat: implement comprehensive flutter protection system for AC sensors
    [Configuration.h]
2025-12-09 fix: update AC current sensors link for accuracy
2025-12-18 fix: update gate orientation configuration to set all gates as open at max position
    [Configuration.h]
2026-01-04 Add KiCad schematics for servo shield for blast gates (circuit implemented and tested working)
    [sss.kicad_pcb, sss.kicad_sch]
